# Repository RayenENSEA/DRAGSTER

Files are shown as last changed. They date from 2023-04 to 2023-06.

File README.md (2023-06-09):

# Rapport Projet DRAGSTER
#  Introduction
  L'objectif de ce projet consiste en la réalisation d'un Dragster, un type de véhicule de course extrêmement rapide, conçu spécifiquement pour des accélérations fulgurantes sur de courtes distances. Ces machines de course impressionnantes sont souvent propulsées par des moteurs surpuissants, capables de générer une grande puissance en un temps très court. 
 
 L'aspect clé de notre projet est l'autonomie du Dragster. Contrairement à un véhicule télécommandé traditionnel, qui dépend d'un opérateur pour le contrôle, notre dragster sera muni d'un bouton poussoir ainsi que de capteurs tels qu'un accéléromètre afin d'assurer une trajectoire droite déclenchée automatiquement sur quelques mètres.
  
# Objectifs du projet
* Réaliser un PCB fonctionnel permettant d'être relié aux composants du Dragster
* Faire fonctionner le véhicule pour qu'il puisse avancer de manière autonome
* Faire avancer le véhicule sur une trajectoire droite de 10m
* Faire avancer le véhicule sur une trajectoire droite de 10m le plus rapidement possible

# Ressources utilisées
## Matériel à disposition :
* Robitronic Moteur Brushless R01230 3000kV
* Gens Ace Batterie 11,1V GEA45003S60X9
* Servomoteur Dynamiel XL-320
* Microcontrôleur STM32L412KBTx
* Variateur Brushless R01221 50A
* Châssis du Dragster ainsi que les deux roues arrière et la roue avant plus petite que les deux autres

## Ressources numériques :
* Github
* KiCad pour la réalisation des schematics et PCB 
* STM32CubeIDE pour la réalisation de la partie Software
* Draw.io pour la réalisation de schémas
* Redmine pour distribuer les tâches et contruire le diagramme de Gantt

# Réalisation

## PCB et Schematics
À partir du schéma hardware ainsi que les composants énoncés dans la datasheet, il a été possible de réaliser un schematic à l'aide de Kicad. Ce schematic reprend les fonctions énoncées dans le schéma hardware. Nous avons eu besoin de consulter les datasheets pour réaliser les montages impliquant notamment les régulateurs à découpage MAX5033DUSA+ pour les tensions 7.4 V et  3.3 V.

Le schéma hardware est disponible sous le nom "Schéma Hardaware.drawio" dans le dossier suivant : https://github.com/RayenENSEA/DRAGSTER/tree/main/Hardware.

## Régulateur à découpage
Comme détaillé precedemment, notre projet comprennait la réalisation de 2 régulateurs pour obtenir les tensions 7.4 V et  3.3 V.
Nos professeurs nous ont conseillés d'opter pour des régulateurs à découpage plutôt que pour des régulateurs linéaires LDO.

En effet, bien que plus compliqués à réaliser, les régulateurs à découpage ont un rendement compris entre 80 % et 90 %, bien plus grand que les régulateurs linéaires. Ces derniers ont en plus la mauvaise caractéristique de dissiper beaucoup de chaleur.

Cependant, la compléxité des régulateurs à découpage est plus élevée car ils necessitent plusieurs composants pour leur réalisation : des inductances, des diodes et des condensateurs de filtrage ainsi que le circuit intégré.
C'est donc pour son efficacité que le régulateur à découpage a plus judicieusement été choisi pour réaliser notre projet.

## Partie software
Ce projet permet de contrôler à la fois un servomoteur Dynamixel XL-320 et un driver de moteur synchrone 50A en utilisant la carte STM32L412KBT3. 
Il utilise l'environnement de développement STM32CubeIDE. 
Voici la description détaillée :  https://github.com/RayenENSEA/DRAGSTER/blob/main/Software/README.md

## Notes en cours de projet
* Liste des composants : https://github.com/RayenENSEA/DRAGSTER/wiki/Liste-des-composants
* Notes globales : https://github.com/RayenENSEA/DRAGSTER/wiki/Notes
* Point avec les professeurs : https://github.com/RayenENSEA/DRAGSTER/wiki/Point-prof-11.04

# Difficultés rencontrées 
* Nous avons fait face à plusieurs difficultés pour la réalisation du PCB, notamment par rapport au routage au vu de la taille de la carte et des composants à utiliser
* Il y a eu des difficultés au moment de tester la carte puisque nous avons constater pendant la soudure des composants des défauts compromettant le fonctionnement de la carte
* En raison du retard de la carte PCB, nous rencontrons des difficultés pour tester tous les codes que nous avons développés avec les autres composants. Cela nous a empêché de réaliser l'étude d'asservissement et d'améliorer les performances des moteurs.
* Les séances de soudure étaient très enrichissantes, nous avons découvert la technique de soudage sur PCB. En soudant des petits composants, il y a eu quelques court-circuits au début.
* Le professeur nous a ensuite conseillé d'essayer une 2ème version du PCB (plaque sans le vernis) pour réduire les risques de dysfonctionnement de la carte.
* Les régulateurs de tension ne fonctionnaient pas comme nous le souhaitions lorsqu'ils étaient à vide ou qu'il y avait une petite charge. Il y avait de courtes phases de régulation puis la tension affichée était celle de l'alimentation.
* Nous avons quand même tenu à terminer le soudage des composants sur la carte pour observer le résultat final et plusieurs composants comme les LEDs fonctionnaient comme prévu.

# Enjeux environnementaux
* 1 - Votre projet favorise-t-il des changements dans les modes de production et de consommation en vue de les rendre plus viables et plus responsables sur les plans social et environnemental ?
 
Notre projet peut avoir un certain impact en faveur de changements dans les modes de production et de consommation premièrement par l'utilisation d'un Dragster fonctionnant avec un moteur éléctrique autonome. L'utilisation de moteurs éléctrique permet la réduction d'émission de gaz à effet de serre et permet donc de démontrer l'efficacité des technologies de propulsion éléctrique. L'exploitation des ressources utilisées permet au projet de pouvoir être réutilisé dans d'autres circonstances et sensibilise donc à la mobilité éléctrique en mettant l'accent sur la technologie de pointe et les performances écologiques concernant la mobilité durable.

* 2 - Quelle réflexion avez-vous mené au cours de ce projet autour de la réutilisation possible d'éléments matériels après votre projet ?

Lors de ce projet, nous avons pris en compte plusieurs points concernant cette question. En effet, la conception du Dragster est modulaire, ce qui rend plus facile le démontage
et la récupération éventuelle de composants individuels qui peuvent être réutilisés dans d'autres projets ou réparer si besoin. L'usage de composant standardisé comme le microcontrôleur permet de maximiser le potentiel de réutilisation, les composants peuvent être utilisés dans de nombreux projets ce qui augmente la chance de les intégrer dans d'autres systèmes à l'avenir.
La documentation nécessaire concernant les schematics, les codes sources et les instructions de montages peuvent également permettre une réutilisation approprié des éléments matériels du projet.
Finalement, si des matériaux ne peuvent être recyclés ou réparer, il est possible de les recycler correctement, comme les métaux ou les circuits imprimés pouvant être transformés en nouvelles ressources dans l'optique de réduire les déchets éléctroniques.

# Présentation soutenance

[Dragster project.pdf](https://github.com/RayenENSEA/DRAGSTER/files/11707936/Dragster.project.pdf)

Lors de la présentation de notre projet, nous avons réussi à montrer une maquette complète avec les différents composants et à les alimenter avec les bonnes tensions. 

En effet, nous avons eu la bonne surprise de découvrir que les régulateurs agissaient de manière correcte lorsque nous avons connecté toutes les pièces entre elles. De plus, après un ultime essai de téléversement du code vers le microcontrolleur, celui-ci a également fonctionné, ce qui nous a permis de réaliser une démonstration du bon fonctionnement d'une partie de la maquette et une suite possible d'évolution et d'amélioration du Dragster project.

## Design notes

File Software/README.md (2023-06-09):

# Contrôle du servomoteur Dynamixel XL-320 et du driver de moteur synchrone 50A avec la carte STM32L412KBT3

Ce projet permet de contrôler à la fois un servomoteur Dynamixel XL-320 et un driver de moteur synchrone 50A en utilisant la carte STM32L412KBT3. 
Il utilise l'environnement de développement STM32CubeIDE.

## Environnement de développement :
   l'IDE STM32CubeIDE.

## Configuration des broches GPIO :
### - Pour le servo-moteur :
  Connection de la broche de signal PMW du servo-moteur à la broche PA0 sur la carte STM32L412KBT3. 
  Pour les autres broches de servo la broche d'alimentation est connectée avec +7.5V et GND avec le GND de la carte.

### - Pour le driver de moteur brushless
  Connection de la broche de signal PMW du driver de moteur brushless à la broche PA2 sur la carte STM32L412KBT3. 
  Pour les autres broches, la broche d'alimentaion et connecter avec 12V et GND avec GND de la carte.

## Contrôle du servomoteur :
- Utilisation des fonctions fournies pour envoyer des commandes au servomoteur la position et la vitesse.

## Contrôle du driver de moteur synchrone :
- Utilisation des broches GPIO configurées précédemment pour envoyer les signaux de contrôle nécessaires au driver.
- Implémentation des fonctions de contrôle appropriées pour démarrer/arrêter le moteur, régler la vitesse, etc.

## Intégration et exécution :
- Combinez les codes de contrôle du servomoteur et du driver de moteur synchrone dans le programme principal.
- Televersement du code final sur la carte a l'aide du debuggeur STLINK.

## Test et débogage :
- Connection de la carte STM32L412KBT3 au servomoteur Dynamixel XL-320 et au driver de moteur synchrone.
- Exécution du programme sur la carte et vérification si le servomoteur et le moteur synchrone fonctionnent comme prévu.
- Utilisation des fonctionnalités de débogage de STM32CubeIDE en cas de problèmes pour identifier et résoudre les erreurs.

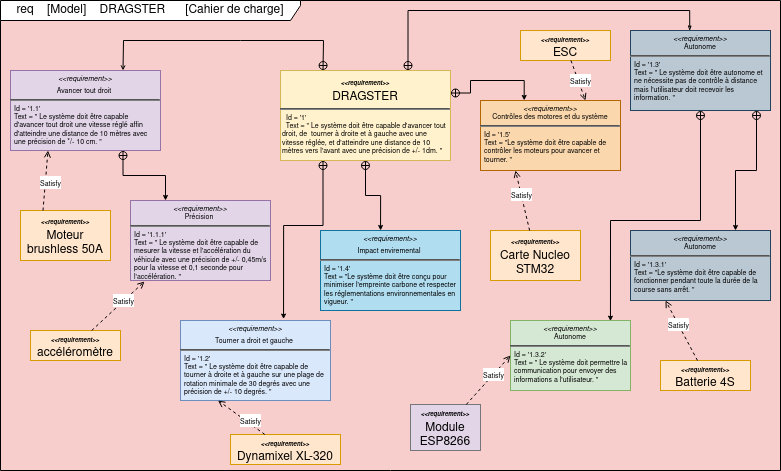
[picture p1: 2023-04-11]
cahier de charge.drawio.png

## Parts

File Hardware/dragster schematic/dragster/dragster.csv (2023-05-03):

Source: | C:\Users\Imad\Desktop\DRAGSTER-main\Hardware\dragster schematic\dragster\dragster.kicad_sch
Date: | 03/05/2023 13:06:15
Tool: | Eeschema 7.0.1
Generator: | C:\Program Files\KiCad\7.0\bin\scripting\plugins/bom_csv_grouped_by_value.py
Component Count: | 51
Collated Components:
Item | Qty | Reference(s) | Value | LibPart | Footprint | Datasheet | DNP
1 | 5 | C1, C10, C11, C12, C13 | 100n | Device:C_Small | Capacitor_SMD:C_0603_1608Metric_Pad1.08x0.95mm_HandSolder | ~
2 | 1 | C2 | 47u | Device:C_Small | Capacitor_SMD:C_0603_1608Metric_Pad1.08x0.95mm_HandSolder | ~
3 | 3 | C3, C6, C7 | 47uF | Device:C_Polarized_Small | Capacitor_SMD:C_0603_1608Metric_Pad1.08x0.95mm_HandSolder | ~
4 | 2 | C4, C9 | 33uF | Device:C_Polarized_Small | Capacitor_SMD:C_0603_1608Metric_Pad1.08x0.95mm_HandSolder | ~
5 | 2 | C5, C8 | 0.1u | Device:C_Small | Capacitor_SMD:C_0603_1608Metric_Pad1.08x0.95mm_HandSolder | ~
6 | 5 | D1, D4, D5, D6, D7 | LED_Small | Device:LED_Small | LED_SMD:LED_0603_1608Metric_Pad1.05x0.95mm_HandSolder | ~
7 | 2 | D2, D3 | D_Schottky | Device:D_Schottky | Diode_SMD:D_2114_3652Metric_Pad1.85x3.75mm_HandSolder | ~
8 | 4 | H1, H2, H3, H4 | MountingHole_Pad | Mechanical:MountingHole_Pad | MountingHole:MountingHole_3.2mm_M3_DIN965_Pad | ~
9 | 3 | J1, J2, J6 | Conn_01x02 | Connector_Generic:Conn_01x02 | Connector_JST:JST_XH_B2B-XH-A_1x02_P2.50mm_Vertical | ~
10 | 1 | J3 | Conn_02x07_Odd_Even | Connector_Generic:Conn_02x07_Odd_Even | Connector_PinHeader_1.27mm:PinHeader_2x07_P1.27mm_Vertical_SMD | ~
11 | 1 | J4 | Conn_01x08 | Connector_Generic:Conn_01x08 | Connector_PinSocket_2.54mm:PinSocket_1x08_P2.54mm_Vertical | ~
12 | 1 | J5 | Conn_01x03 | Connector_Generic:Conn_01x03 | Connector_JST:JST_XH_B3B-XH-A_1x03_P2.50mm_Vertical | ~
13 | 2 | L1, L2 | 220uH | Device:L_Small | Inductor_SMD:L_0805_2012Metric_Pad1.05x1.20mm_HandSolder | ~
14 | 5 | R1, R11, R13, R14, R15 | 220 | Device:R_Small | Resistor_SMD:R_0603_1608Metric_Pad0.98x0.95mm_HandSolder | ~
15 | 4 | R2, R3, R7, R8 | R_Small | Device:R_Small | Resistor_SMD:R_0603_1608Metric_Pad0.98x0.95mm_HandSolder | ~
16 | 2 | R4, R12 | 100k | Device:R_Small | Resistor_SMD:R_0603_1608Metric_Pad0.98x0.95mm_HandSolder | ~
17 | 1 | R5 | 68k | Device:R_Small | Resistor_SMD:R_0603_1608Metric_Pad0.98x0.95mm_HandSolder | ~
18 | 1 | R6 | 13.5k | Device:R_Small | Resistor_SMD:R_0603_1608Metric_Pad0.98x0.95mm_HandSolder | ~
19 | 1 | R9 | 22k | Device:R_Small | Resistor_SMD:R_0603_1608Metric_Pad0.98x0.95mm_HandSolder | ~
20 | 1 | R10 | 13k | Device:R_Small | Resistor_SMD:R_0603_1608Metric_Pad0.98x0.95mm_HandSolder | ~
21 | 1 | SW2 | SW_Push | Switch:SW_Push | Button_Switch_SMD:SW_SPST_B3U-1000P | ~
22 | 1 | U1 | STM32L412KBTx | MCU_ST_STM32L4:STM32L412KBTx | Package_QFP:LQFP-32_7x7mm_P0.8mm | https://www.st.com/resource/en/datasheet/stm32l412kb.pdf
23 | 2 | U2, U4 | MAX5033DUSA+T | MAX5033DUSA_T:MAX5033DUSA+T | Package_SO:SSO-8_6.8x5.9mm_P1.27mm_Clearance7mm

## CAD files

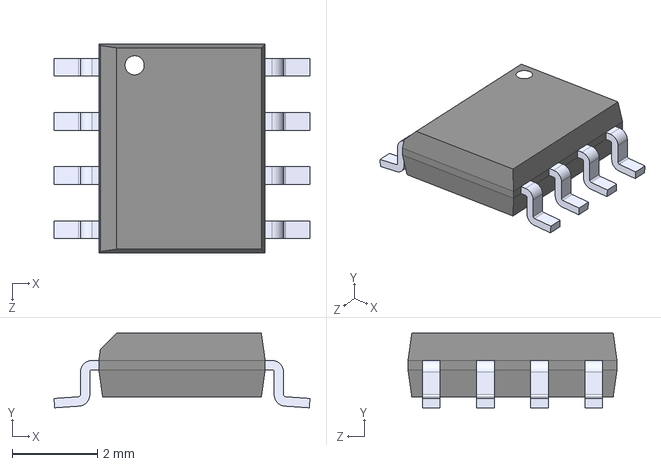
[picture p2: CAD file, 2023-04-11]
Hardware/Symbole dragster/MAX5033DUSA_T/MAX5033DUSA_T.step
6.00 x 1.75 x 4.90 mm

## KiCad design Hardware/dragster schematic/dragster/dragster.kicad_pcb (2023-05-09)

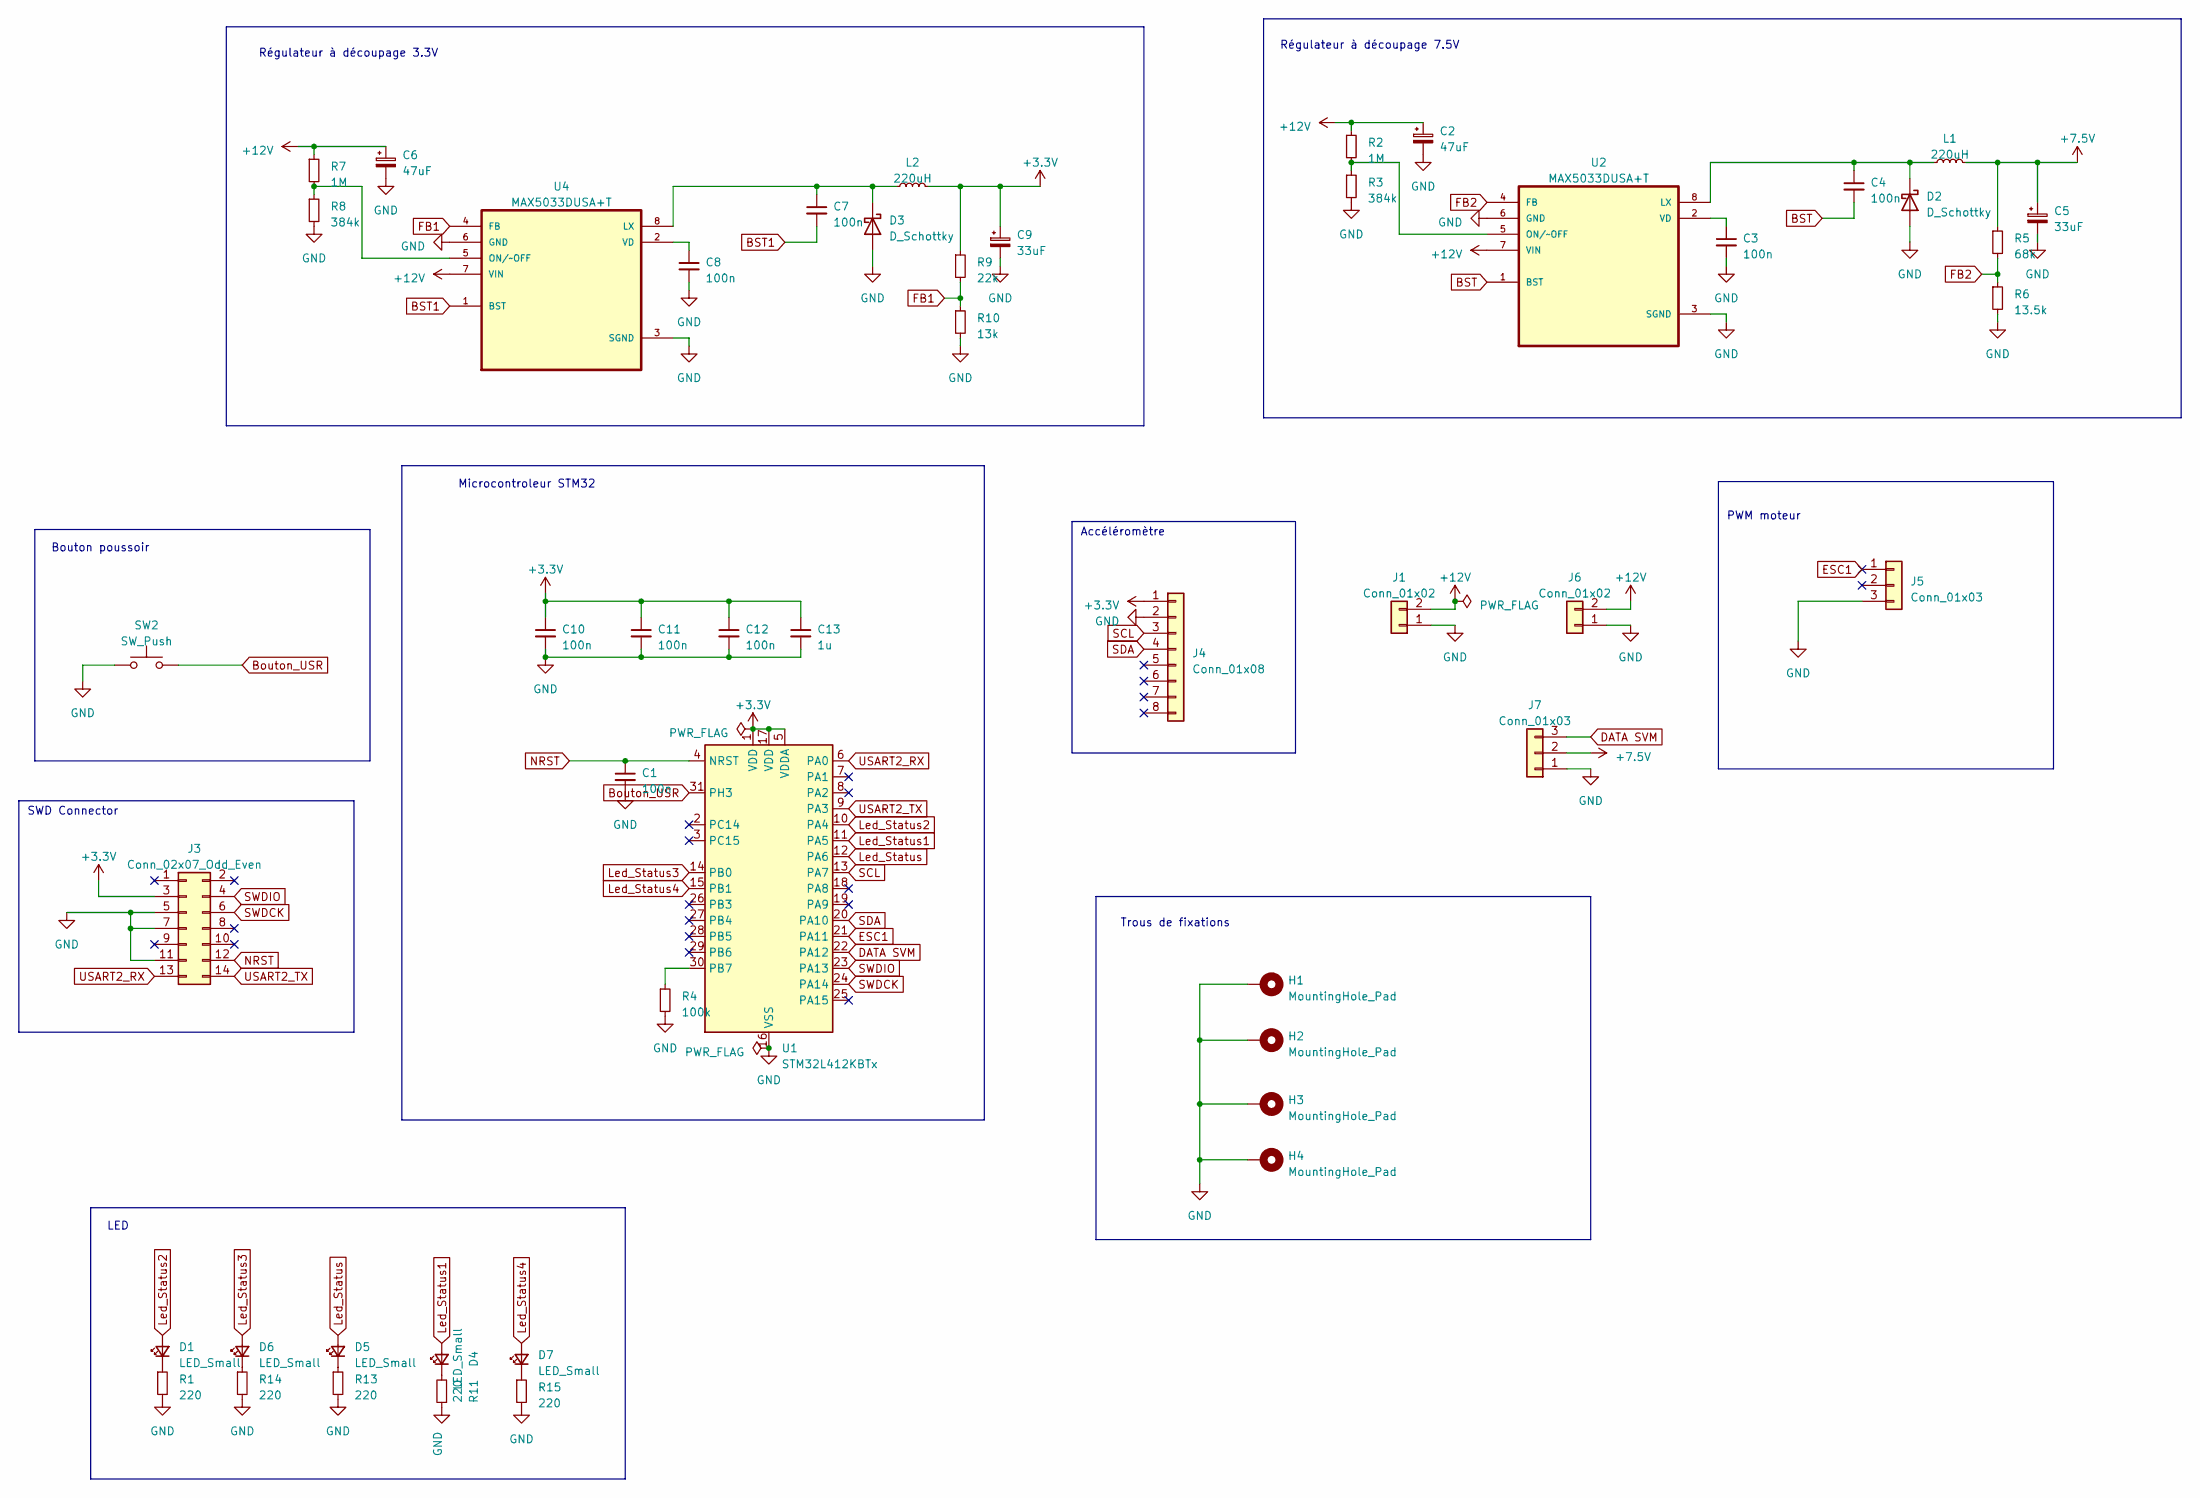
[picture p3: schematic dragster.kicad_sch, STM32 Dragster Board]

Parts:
C1, C3, C4, C7, C8, C10, C11, C12: 100n; C_0603_1608Metric_Pad1.08x0.95mm_HandSolder
C2, C6: 47uF; C_Elec_6.3x5.4
C5, C9: 33uF; C_Elec_6.3x5.4
C13: 1u; C_0603_1608Metric_Pad1.08x0.95mm_HandSolder
D1, D4, D5, D6, D7: LED_Small; LED_0603_1608Metric_Pad1.05x0.95mm_HandSolder
D2, D3: D_Schottky; D_2114_3652Metric_Pad1.85x3.75mm_HandSolder
H1, H2, H3, H4: MountingHole_Pad; MountingHole_3.2mm_M3_DIN965_Pad
J1, J6: Conn_01x02; AMASS_XT60-M_1x02_P7.20mm_Vertical
J3: Conn_02x07_Odd_Even; PinHeader_2x07_P1.27mm_Vertical_SMD
J4: Conn_01x08; PinSocket_1x08_P2.54mm_Vertical
J5, J7: Conn_01x03; JST_XH_B3B-XH-A_1x03_P2.50mm_Vertical
L1, L2: 220uH; L_12x12mm_H6mm
R1, R11, R13, R14, R15: 220; R_0603_1608Metric_Pad0.98x0.95mm_HandSolder
R2, R7: 1M; R_0603_1608Metric_Pad0.98x0.95mm_HandSolder
R3, R8: 384k; R_0603_1608Metric_Pad0.98x0.95mm_HandSolder
R4: 100k; R_0603_1608Metric_Pad0.98x0.95mm_HandSolder
R5: 68k; R_0603_1608Metric_Pad0.98x0.95mm_HandSolder
R6: 13.5k; R_0603_1608Metric_Pad0.98x0.95mm_HandSolder
R9: 22k; R_0603_1608Metric_Pad0.98x0.95mm_HandSolder
R10: 13k; R_0603_1608Metric_Pad0.98x0.95mm_HandSolder
SW2: SW_Push; SW_SPST_B3U-1000P
U1: STM32L412KBTx; LQFP-32_7x7mm_P0.8mm
U2, U4: MAX5033DUSA+T; SOIC-8_3.9x4.9mm_P1.27mm

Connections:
+3.3V: C9.1, C10.1, C11.1, C12.1, C13.1, J3.3, J4.1, L2.2, R9.1, U1.1 (VDD), U1.5 (VDDA), U1.17 (VDD)
+7.5V: C5.1, J7.2, L1.2, R5.1
+12V: C2.1, C6.1, J1.2, J6.2, R2.1, R7.1, U2.7 (VIN), U4.7 (VIN)
BST: C4.2, U2.1 (BST)
BST1: C7.2, U4.1 (BST)
Bouton_USR: SW2.2, U1.31 (PH3)
DATA SVM: J7.3, U1.22 (PA12)
ESC1: J5.1, U1.21 (PA11)
FB1: R9.2, R10.1, U4.4 (FB)
FB2: R5.2, R6.1, U2.4 (FB)
GND: C1.2, C2.2, C3.2, C5.2, C6.2, C8.2, C9.2, C10.2, C11.2, C12.2, C13.2, D2.2 (A), D3.2 (A), H1.1, H2.1, H3.1, H4.1, J1.1, J3.5, J3.7, J3.11, J4.2, J5.3, J6.1, J7.1, R1.2, R3.2, R4.2, R6.2, R8.2, R10.2, R11.1, R13.2, R14.2, R15.2, SW2.1, U1.16 (VSS), U1.32 (VSS), U2.3 (SGND), U2.6 (GND), U4.3 (SGND), U4.6 (GND)
Led_Status: D5.2 (A), U1.12 (PA6)
Led_Status1: D4.2 (A), U1.11 (PA5)
Led_Status2: D1.2 (A), U1.10 (PA4)
Led_Status3: D6.2 (A), U1.14 (PB0)
Led_Status4: D7.2 (A), U1.15 (PB1)
NRST: C1.1, J3.12, U1.4 (NRST)
unnamed: D1.1 (K), R1.1
unnamed: C4.1, D2.1 (K), L1.1, U2.8 (LX)
unnamed: C7.1, D3.1 (K), L2.1, U4.8 (LX)
unnamed: D4.1 (K), R11.2
unnamed: D5.1 (K), R13.1
unnamed: D6.1 (K), R14.1
unnamed: D7.1 (K), R15.1
unnamed: R4.1, U1.30 (PB7)
unnamed: R2.2, R3.1, U2.5 (ON/~OFF)
unnamed: C3.1, U2.2 (VD)
unnamed: R7.2, R8.1, U4.5 (ON/~OFF)
unnamed: C8.1, U4.2 (VD)
SCL: J4.3, U1.13 (PA7)
SDA: J4.4, U1.20 (PA10)
SWDCK: J3.6, U1.24 (PA14)
SWDIO: J3.4, U1.23 (PA13)
USART2_RX: J3.13, U1.6 (PA0)
USART2_TX: J3.14, U1.9 (PA3)

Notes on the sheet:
Régulateur à découpage 3.3V
PWM moteur
LED
Régulateur à découpage 7.5V
Accéléromètre
Microcontroleur STM32
Trous de fixations
Bouton poussoir
SWD Connector

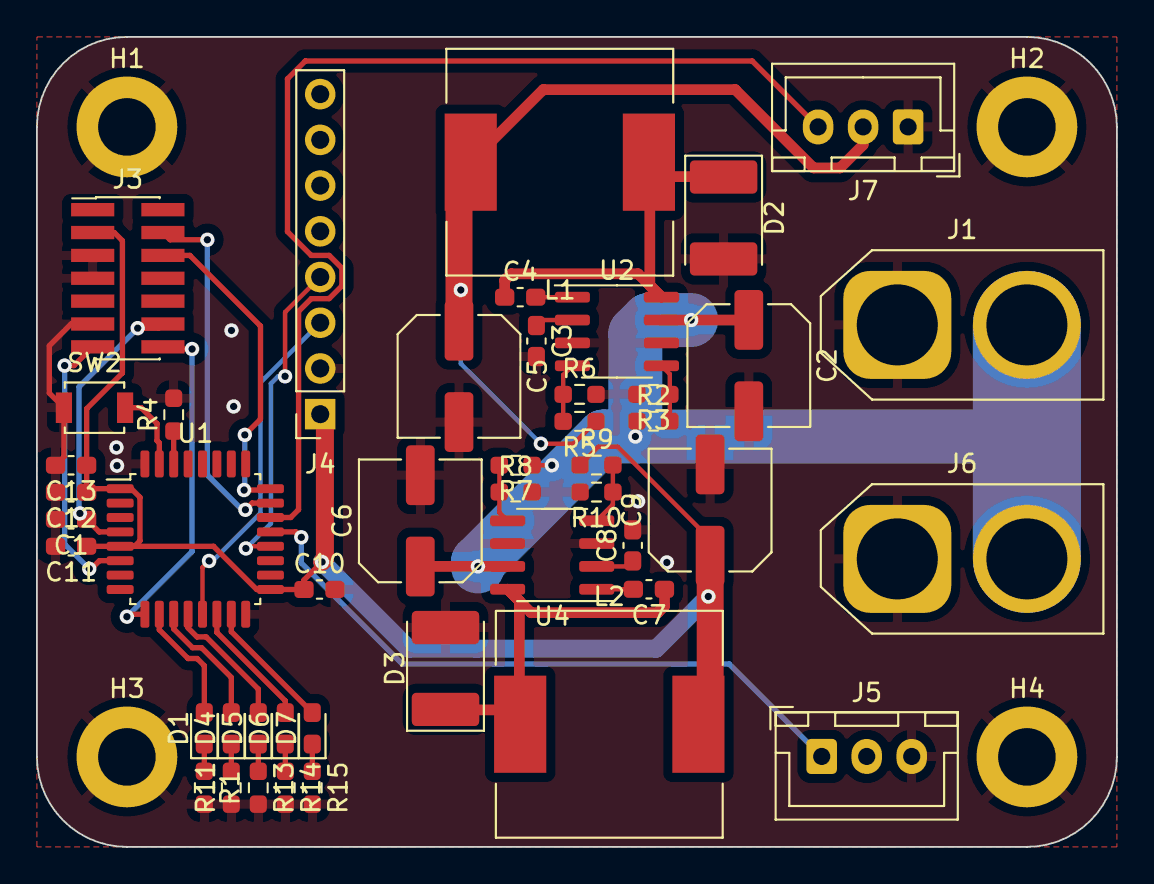
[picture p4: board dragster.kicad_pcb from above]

Board: 2 copper layers, 60.0 x 45.0 mm, 50 parts (0 on the bottom side), 35 nets.

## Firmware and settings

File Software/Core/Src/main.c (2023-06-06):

/* Ces directives d'inclusion permettent d'importer les fichiers d'en-tête nécessaires pour utiliser les bibliothèques
et les fonctionnalités spécifiques à la carte STM32 */
#include "main.h"
#include "stm32l4xx_hal.h"
#include "stm32l4xx_hal_tim.h"
#include "SystemClock_Config.c"
#include "PWM_Init.c"


/* Ces déclarations créent des variables de type TIM_HandleTypeDef qui seront utilisées pour configurer et contrôler les
timers TIM2 et TIM1, respectivement */
TIM_HandleTypeDef htim2;
TIM_HandleTypeDef htim1;


/* La fonction main est le point d'entrée du programme. Elle appelle les fonctions HAL_Init pour initialiser la bibliothèque
HAL, SystemClock_Config pour configurer l'horloge du système, et PWM_Init pour initialiser les timers et les broches
GPIO utilisés pour le contrôle du servo-moteur et du driver de moteur brushless */
int main(void)
{
  HAL_Init();
  SystemClock_Config();
  PWM_Init();


/* Cette boucle while représente la partie principale du programme qui s'exécute en boucle infinie. Elle contient des
fonctions de contrôle du servo-moteur et du driver de moteur brushless. Les fonctions HAL_TIM_PWM_Start et
HAL_TIM_PWM_Stop sont utilisées pour démarrer et arrêter les canaux PWM respectifs pour contrôler les dispositifs  */
  while (1)
  {
	// Faire tourner le servo-moteur à 30 degrés
	// Utiliser la fonction HAL_TIM_PWM_Start() pour démarrer le canal PWM du servo-moteur
	// et HAL_TIM_PWM_Stop() pour arrêter le canal PWM lorsque le mouvement est terminé

    HAL_TIM_PWM_Start(&htim2, TIM_CHANNEL_1);
    HAL_Delay(1000);  // Délai pour maintenir la position du servo-moteur '1s'
    HAL_TIM_PWM_Stop(&htim2, TIM_CHANNEL_1);


    sConfigOC = 1700; // position intial du moteur
    HAL_TIM_PWM_ConfigChannel(&htim2, &sConfigOC, TIM_CHANNEL_1);
    HAL_TIM_PWM_Start(&htim2, TIM_CHANNEL_1);
    HAL_Delay(2000);


    // Contrôle du driver de moteur brushless
    // Utilison la fonction HAL_TIM_PWM_Start() pour démarrer le canal PWM du driver de moteur
    // et HAL_TIM_PWM_Stop() pour arrêter le canal PWM lorsque le contrôle est terminé
    HAL_TIM_PWM_Start(&htim1, TIM_CHANNEL_1);
    HAL_Delay(2000);  // Délai pour maintenir le contrôle du driver de moteur brushless
    HAL_TIM_PWM_Stop(&htim1, TIM_CHANNEL_1);
  }
}




/* La fonction Error_Handler est appelée en cas d'erreur. Dans cet exemple, elle met simplement le microcontrôleur en
boucle infinie, ce qui permet de détecter et de gérer les erreurs.Cela conclut l'explication du code fourni. Il s'agit
d'un exemple générique pour le contrôle d'un servo-moteur et d'un driver de moteur brushless à l'aide des timers PWM de
la carte STM32. Vous devrez ajuster les valeurs de pulsation (Pulse) en fonction de votre matériel spécifique */
void Error_Handler(void)
{
  while (1)
  {
    // Gestion des erreurs
  }
}

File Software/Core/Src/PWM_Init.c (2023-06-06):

/* La fonction PWM_Init initialise les timers TIM2 et TIM1 ainsi que les broches GPIO utilisées pour les signaux PWM du
servo-moteur et du driver de moteur brushless. Elle configure les broches GPIO en mode alternatif pour les canaux PWM,
configure les timers avec les paramètres appropriés, et configure les canaux de sortie PWM avec les rapports cycliques
initiaux spécifiés */
#include "stm32l4xx_hal.h"
#include "stm32l4xx_hal_tim.h"
#include "PWM_Init.h"

void PWM_Init(void)
{
  GPIO_InitTypeDef GPIO_InitStruct = {0};
  TIM_MasterConfigTypeDef sMasterConfig = {0};
  TIM_OC_InitTypeDef sConfigOC = {0};

  __HAL_RCC_TIM2_CLK_ENABLE();
  __HAL_RCC_GPIOA_CLK_ENABLE();

  // Configuration des broches GPIO en mode alternatif pour le canal PWM du servo-moteur
  GPIO_InitStruct.Pin = GPIO_PIN_0;
  GPIO_InitStruct.Mode = GPIO_MODE_AF_PP;
  GPIO_InitStruct.Pull = GPIO_NOPULL;
  GPIO_InitStruct.Speed = GPIO_SPEED_FREQ_HIGH;
  GPIO_InitStruct.Alternate = GPIO_AF1_TIM2;
  HAL_GPIO_Init(GPIOA, &GPIO_InitStruct);

  // Configuration du timer TIM2 pour le servo-moteur
  htim2.Instance = TIM2;
  htim2.Init.Prescaler = 0;
  htim2.Init.CounterMode = TIM_COUNTERMODE_UP;
  htim2.Init.Period = 19999;
  htim2.Init.ClockDivision = TIM_CLOCKDIVISION_DIV1;
  if (HAL_TIM_PWM_Init(&htim2) != HAL_OK)
  {
    Error_Handler();
  }

  sMasterConfig.MasterOutputTrigger = TIM_TRGO_RESET;
  sMasterConfig.MasterSlaveMode = TIM_MASTERSLAVEMODE_DISABLE;
  if (HAL_TIMEx_MasterConfigSynchronization(&htim2, &sMasterConfig) != HAL_OK)
  {
    Error_Handler();
  }

  sConfigOC.OCMode = TIM_OCMODE_PWM1;
  sConfigOC.Pulse = 1500;  // Rapport cyclique initial pour le servo-moteur
  sConfigOC.OCPolarity = TIM_OCPOLARITY_HIGH;
  sConfigOC.OCFastMode = TIM_OCFAST_DISABLE;
  if (HAL_TIM_PWM_ConfigChannel(&htim2, &sConfigOC, TIM_CHANNEL_1) != HAL_OK)
  {
    Error_Handler();
  }

  __HAL_RCC_TIM1_CLK_ENABLE();
  __HAL_RCC_GPIOA_CLK_ENABLE();

  // Configuration des broches GPIO en mode alternatif pour le canal PWM du driver de moteur brushless
  GPIO_InitStruct.Pin = GPIO_PIN_2;
  GPIO_InitStruct.Mode = GPIO_MODE_AF_PP;
  GPIO_InitStruct.Pull = GPIO_NOPULL;
  GPIO_InitStruct.Speed = GPIO_SPEED_FREQ_HIGH;
  GPIO_InitStruct.Alternate = GPIO_AF1_TIM15; // Utilisation de GPIO_AF1_TIM15 pour PA2
  HAL_GPIO_Init(GPIOA, &GPIO_InitStruct);

  // Configuration du timer TIM1 pour le driver de moteur brushless
  htim1.Instance = TIM1;
  htim1.Init.Prescaler = 0;
  htim1.Init.CounterMode = TIM_COUNTERMODE_UP;
  htim1.Init.Period = 9999;
  htim1.Init.ClockDivision = TIM_CLOCKDIVISION_DIV1;
  if (HAL_TIM_PWM_Init(&htim1) != HAL_OK)
  {
    Error_Handler();
  }

  sMasterConfig.MasterOutputTrigger = TIM_TRGO_RESET;
  sMasterConfig.MasterSlaveMode = TIM_MASTERSLAVEMODE_DISABLE;
  if (HAL_TIMEx_MasterConfigSynchronization(&htim1, &sMasterConfig) != HAL_OK)
  {
    Error_Handler();
  }

  sConfigOC.OCMode = TIM_OCMODE_PWM1;
  sConfigOC.Pulse = 5000;  // Rapport cyclique initial pour le driver de moteur brushless
  sConfigOC.OCPolarity = TIM_OCPOLARITY_HIGH;
  sConfigOC.OCFastMode = TIM_OCFAST_DISABLE;
  if (HAL_TIM_PWM_ConfigChannel(&htim1, &sConfigOC, TIM_CHANNEL_1) != HAL_OK)
  {
    Error_Handler();
  }
}

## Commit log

2023-04-03 Diagramme de Cahier de Charge
2023-04-03 cahier de charge
2023-04-03 cahier de charge.drawio
2023-04-03 cahier de charge (en cours)
2023-04-09 Mettre à jour cahier de charge.drawio.png
2023-04-11 Update cahier de charge.drawio.png
